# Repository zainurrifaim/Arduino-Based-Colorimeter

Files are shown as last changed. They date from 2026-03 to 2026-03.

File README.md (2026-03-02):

# 🎨 Arduino-Based Colorimeter

> **IoT RGB Colorimeter (LDR + LED)** — A cost-effective, educational light absorption measurement system

A simple yet powerful colorimeter built using an Arduino, an RGB LED, and a Light Dependent Resistor (LDR). This project supports both **physical hardware implementation** and **Tinkercad simulation**, making it perfect for learning and prototyping.

---

## 📑 Contents

- [Objective](#-objective)
- [Specifications](#-specifications)
- [Features](#-features)
- [Mathematical Principle](#-mathematical-principle)
- [Try It Out](#-try-it-out)
- [How to Use](#-how-to-use)
- [Project Structure](#-project-structure)

---

## 📋 Objective

Measure the **absorbance of liquid samples** across three primary wavelengths (Red, Green, and Blue) using the **Beer-Lambert Law principle**. This device quantifies how much light is absorbed by a solution, enabling:

- Determination of substance concentration
- Color characteristic analysis  
- Educational IoT demonstrations

---

## 🔧 Specifications

### Hardware Components

| Component | Description |
|---|---|
| **Microcontroller** | Arduino Uno (or compatible) |
| **Sensor** | 3-Pin LDR Module (or discrete LDR with 10kΩ resistor) |
| **Light Source** | RGB LED (Common Cathode recommended) |
| **Display** | 16×2 I2C LCD (Address 0x27) |
| **Controls** | 2× Tactile Push Buttons |
| **Resistors** | 3× 220Ω (LED protection) + 1× 10kΩ (optional, for discrete LDR) |

### Wiring and Pinout

#### 1️⃣ 3-Pin LDR Module

| Module Pin | Arduino Connection |
|---|---|
| **VCC** | 5V |
| **GND** | GND |
| **OUT (or S)** | A0 |

#### 2️⃣ RGB LED (Common Cathode)

| LED Pin | Arduino Connection | Details |
|---|---|---|
| **Common (Longest)** | GND | — |
| **Red Pin** | Pin 2 | via 220Ω resistor |
| **Green Pin** | Pin 3 | via 220Ω resistor |
| **Blue Pin** | Pin 4 | via 220Ω resistor |

#### 3️⃣ I2C LCD Display

| LCD Pin | Arduino Connection |
|---|---|
| **GND** | GND |
| **VCC** | 5V |
| **SDA** | A4 |
| **SCL** | A5 |

#### 4️⃣ Control Buttons

| Button | Arduino Pin | Other Connection |
|---|---|---|
| **Blank** | Pin 8 | GND |
| **Read** | Pin 9 | GND |

---

## ✨ Features

- **🌈 Multi-Spectrum Analysis** — Measures absorbance for Red, Green, and Blue wavelengths individually

- **⚙️ Intelligent Calibration** — Dedicated "Blank" mode to set 100% transmission baseline using a reference solution

- **📊 Signal Stability** — Digital averaging (multiple samples per reading) to filter sensor noise and electrical interference

- **🔄 Dual-Platform Support**
  - `colorimeter.ino` — Optimized for 3-pin LDR modules (Physical hardware)
  - `colorimeter_tinkercad.ino` — Adjusted for discrete 2-pin photoresistors (Tinkercad simulations)

- **💻 Real-time Feedback** — LCD interface with step-by-step instructions and instant numerical results (0.00 to 2.00+ absorbance units)

- **🛡️ Safety Guards** — Software checks prevent division-by-zero errors and prompt if calibration is skipped

---

## 📐 Mathematical Principle

The device calculates absorbance using the **Beer-Lambert Law**:

$$A = \log_{10}\left(\frac{I_{blank}}{I_{sample}}\right)$$

> **Note:** In the physical LDR module setup, the ratio is inverted in code to account for the specific resistance-to-voltage curve of the pre-built module.

---

## 🧪 Try It Out

**[View Interactive Tinkercad Simulation](https://www.tinkercad.com/things/clHeNK5QqYa-colorimeter/editel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)**

Test the logic and virtual circuit without building physical hardware!

---

## 🚀 How to Use

| Step | Action | Details |
|---|---|---|
| **1️⃣ Initialize** | Power the Arduino | Wait for "Ready!" message on LCD |
| **2️⃣ Calibrate** | Insert blank solution + press Pin 8 button | Sets 100% transmission baseline (use clear water) |
| **3️⃣ Measure** | Replace with sample + press Pin 9 button | Measures actual sample absorbance |
| **4️⃣ Analyze** | Read the results | LCD or Serial Monitor displays R, G, B absorbance values |

---

## 📂 Project Structure

```
Arduino-Based Colorimeter/
├── colorimeter/
│   └── colorimeter.ino           # Physical hardware version (3-pin LDR)
├── tinkercad_simulation/
│   └── colorimeter_tinkercad.ino # Simulation version (discrete photoresistor)
├── CAD/                          # 3D models and hardware designs
└── README.md                     # This file
```

---

## 💡 Tips & Troubleshooting

- **Calibration is Key** — Accurate blank readings directly impact measurement accuracy
- **Stable Environment** — Keep ambient light constant during measurements
- **Averaging** — The firmware automatically averages multiple readings to reduce noise
- **Serial Monitor** — Open the Serial Monitor (9600 baud) for detailed debugging info

---

## 📚 References

- **Beer-Lambert Law** — Fundamental principle for absorbance measurement
- **Arduino Documentation** — [arduino.cc](https://www.arduino.cc)
- **I2C LCD Displays** — Standard address 0x27 for 16×2 displays
- **Tinkercad** — [tinkercad.com](https://www.tinkercad.com) for circuit simulation

---

## ⭐ Perfect For

✓ Physics & Chemistry Education  
✓ IoT Projects & Prototyping  
✓ Sensor Integration Learning  
✓ Arduino Skill Development  
✓ DIY Analytical Instruments  

---

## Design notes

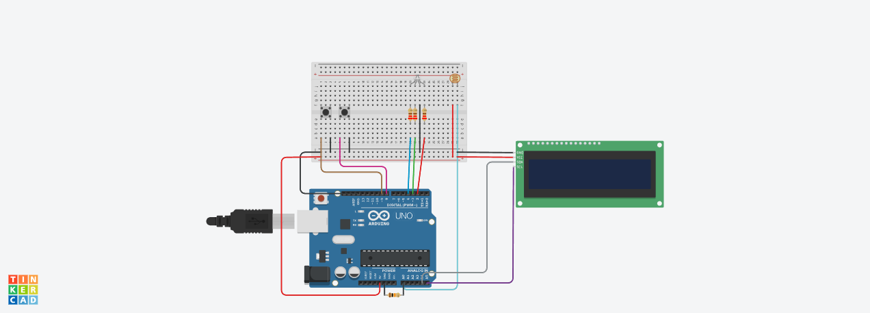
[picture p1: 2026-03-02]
tinkercad_simulation/colorimeter.png

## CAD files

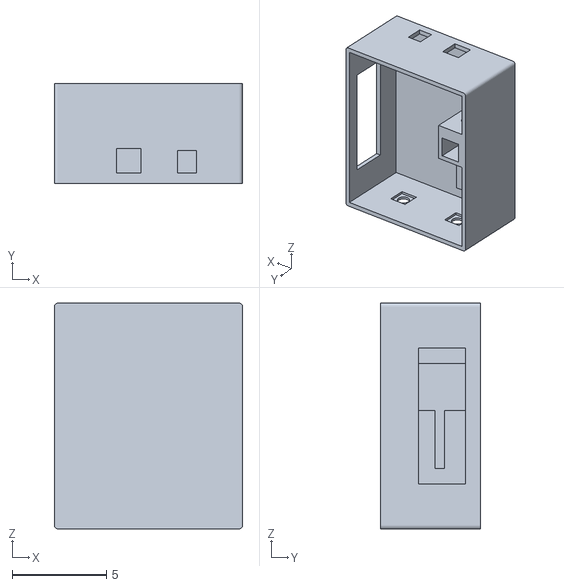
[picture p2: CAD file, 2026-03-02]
CAD/Case Colorymeter.stl
10.0 x 5.30 x 12.0

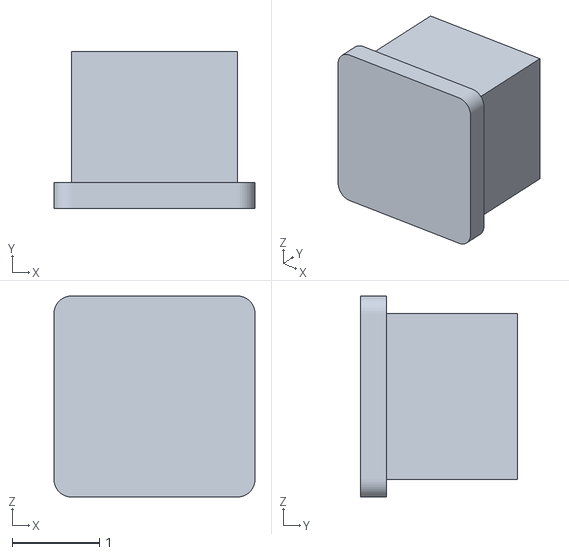
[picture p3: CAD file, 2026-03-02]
CAD/Tutup 2.stl
2.30 x 1.80 x 2.30

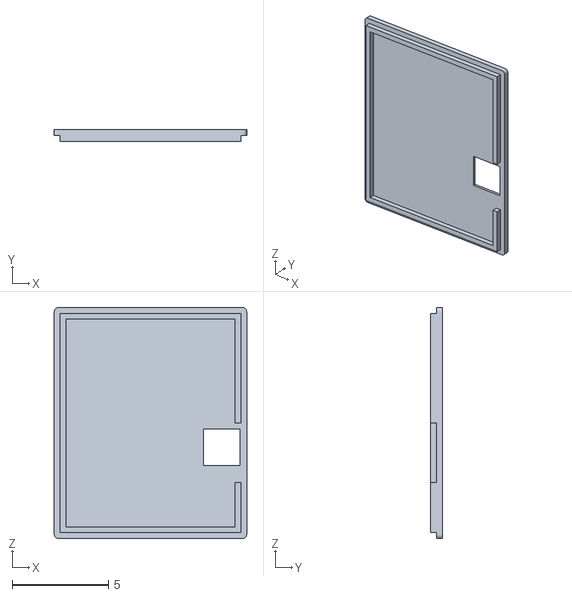
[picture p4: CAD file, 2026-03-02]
CAD/Cover 1 rev.stl
10.0 x 0.6 x 12.0

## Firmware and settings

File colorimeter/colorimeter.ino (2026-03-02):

/**
 * Final Colorimeter Sketch
 * * Description:
 * This code runs a simple colorimeter using an LDR, an RGB LED, and an I2C LCD.
 * It follows the Beer-Lambert law to calculate the absorbance of a sample.
 * * Features:
 * - Two-button operation: one for calibrating with a blank, one for measuring a sample.
 * - Averaging of sensor readings to reduce noise and improve accuracy.
 * - Clear user prompts on a 16x2 I2C LCD display.
 * - Robust button handling with debounce and single-press detection.
 * - Safe absorbance calculation with checks for calibration and division by zero.
 * * Hardware Setup:
 * - Arduino Uno (or similar)
 * - I2C LCD 16x2 (Address 0x27)
 * - Sensor: LDR on pin A0
 * - LEDs: Red on pin 2, Green on pin 3, Blue on pin 4
 * - Buttons: Blank/Calibrate on pin 8, Read/Measure on pin 9
 */

#include <Wire.h>
#include <LiquidCrystal_I2C.h>
#include <math.h> // For the log10() function

// Initialize the LCD display
LiquidCrystal_I2C lcd(0x27, 16, 2);

// --- Configuration Constants ---
const int numReadings = 10;      // Number of sensor readings to average for stability
const int sensorDelay = 10;      // Delay between individual readings (ms)
const int ledStabilizeTime = 50; // Time to wait for LED to reach full brightness

// --- Pin Definitions ---
const int sensorPin = A0;
const int ledRedPin = 2;
const int ledGreenPin = 3;
const int ledBluePin = 4;
const int buttonBlankPin = 8;
const int buttonReadPin = 9;

// --- Global Variables ---
double blankRed = 0, blankGreen = 0, blankBlue = 0;
double sampleRed = 0, sampleGreen = 0, sampleBlue = 0;
double absRed = 0, absGreen = 0, absBlue = 0;

// Flag to track whether calibration has been completed
bool isCalibrated = false;

void setup() {
  Serial.begin(9600);
  
  // Initialize the LCD and turn on the backlight
  lcd.init();
  lcd.backlight();
  lcd.setCursor(0, 0);
  lcd.print("Colorimeter");
  lcd.setCursor(0, 1);
  lcd.print("Initializing...");
  delay(2000);
  lcd.clear();

  // Set pin modes
  pinMode(ledRedPin, OUTPUT);
  pinMode(ledGreenPin, OUTPUT);
  pinMode(ledBluePin, OUTPUT);
  pinMode(sensorPin, INPUT);
  pinMode(buttonBlankPin, INPUT_PULLUP);
  pinMode(buttonReadPin, INPUT_PULLUP);
  
  Serial.println("Colorimeter Ready!");
  lcd.setCursor(0, 0);
  lcd.print("Ready!");
  lcd.setCursor(0, 1);
  lcd.print("Press Calibrate");
}

void loop() {
  // Check for Blank/Calibrate button press
  if (digitalRead(buttonBlankPin) == LOW) {
    delay(50); // Debounce delay
    calibrateBlank();
    // Wait for the button to be released to prevent re-triggering
    while(digitalRead(buttonBlankPin) == LOW);
  }
  
  // Check for Read/Measure button press
  if (digitalRead(buttonReadPin) == LOW) {
    delay(50); // Debounce delay
    measureSample();
    // Wait for the button to be released
    while(digitalRead(buttonReadPin) == LOW);
  }
}

// Function to handle blank calibration
void calibrateBlank() {
  lcd.clear();
  lcd.setCursor(0, 0);
  lcd.print("Insert Blank...");
  lcd.setCursor(0, 1);
  lcd.print("Calibrating...");
  
  // Take readings for all three colors
  blankRed = averageLDR(ledRedPin);
  blankGreen = averageLDR(ledGreenPin);
  blankBlue = averageLDR(ledBluePin);
  
  isCalibrated = true; // Set the calibration flag
  
  lcd.clear();
  lcd.setCursor(0, 0);
  lcd.print("Calibration OK!");
  Serial.println("Blank Calibration Done!");
  delay(1500);
  
  lcd.clear();
  lcd.print("Ready to Read");
}

// Function to measure sample absorbance
void measureSample() {
  // First, check if calibration has been performed
  if (!isCalibrated) {
    showError("Please Calibrate!");
    return;
  }
  
  lcd.clear();
  lcd.setCursor(0, 0);
  lcd.print("Insert Sample...");
  lcd.setCursor(0, 1);
  lcd.print("Measuring...");
  
  // Take readings for the sample
  sampleRed = averageLDR(ledRedPin);
  sampleGreen = averageLDR(ledGreenPin);
  sampleBlue = averageLDR(ledBluePin);
  
  // Calculate absorbance for each color
  // Absorbance = log10(Sample / Blank)
  // LDR reading is higher for the sample (less light) and lower for the blank (more light).
  // This ensures the absorbance is a positive value.
  absRed   = (sampleRed > 0 && blankRed > 0) ? log10(sampleRed / blankRed) : 0;
  absGreen = (sampleGreen > 0 && blankGreen > 0) ? log10(sampleGreen / blankGreen) : 0;
  absBlue  = (sampleBlue > 0 && blankBlue > 0) ? log10(sampleBlue / blankBlue) : 0;
  
  displayResults();
}

// Function to average LDR readings for a specific LED
double averageLDR(int ledPin) {
  // Ensure all LEDs are off to prevent light interference
  digitalWrite(ledRedPin, LOW);
  digitalWrite(ledGreenPin, LOW);
  digitalWrite(ledBluePin, LOW);
  
  // Turn on the target LED and wait for it to stabilize
  digitalWrite(ledPin, HIGH);
  delay(ledStabilizeTime);
  
  long total = 0;
  for (int i = 0; i < numReadings; i++) {
    total += analogRead(sensorPin);
    delay(sensorDelay);
  }
  
  // Turn the LED off after reading
  digitalWrite(ledPin, LOW);
  
  // Return the average value
  return total / (double)numReadings;
}

// Function to display absorbance results on the LCD and Serial Monitor
void displayResults() {
  lcd.clear();
  
  // Display Red and Green absorbance on the first line
  lcd.setCursor(0, 0);
  lcd.print("R:");
  lcd.print(absRed, 2); // Print with 2 decimal places
  
  lcd.setCursor(8, 0);
  lcd.print("G:");
  lcd.print(absGreen, 2);
  
  // Display Blue absorbance on the second line
  lcd.setCursor(0, 1);
  lcd.print("B:");
  lcd.print(absBlue, 2);
  
  // Print results to Serial Monitor for logging
  Serial.println("Absorbance Readings:");
  Serial.print("R: "); Serial.println(absRed, 2);
  Serial.print("G: "); Serial.println(absGreen, 2);
  Serial.print("B: "); Serial.println(absBlue, 2);

  // The loop() function will wait for the button release, so no extra wait is needed here.
}

// Function to display a temporary error message
void showError(const char* message) {
  lcd.clear();
  lcd.setCursor(0, 0);
  lcd.print("Error:");
  lcd.setCursor(0, 1);
  lcd.print(message);
  delay(2000);
  lcd.clear();
  lcd.print("Ready!");
}

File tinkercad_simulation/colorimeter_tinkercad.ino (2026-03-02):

/**
 * Tinkercad Colorimeter Sketch
 * * Description:
 * This version is specifically adapted for Tinkercad using a discrete 2-pin 
 * photoresistor and a standard voltage divider circuit.
 * * * Tinkercad Hardware Setup:
 * - Arduino Uno
 * - I2C LCD 16x2 (Address 0x27)
 * - LEDs: Red on pin 2, Green on pin 3, Blue on pin 4
 * - Buttons: Blank/Calibrate on pin 8, Read/Measure on pin 9
 * - PHOTO SENSOR WIRING: 
 * - Photoresistor Leg 1: 5V
 * - Photoresistor Leg 2: A0 AND to a 10k Ohm Resistor
 * - 10k Ohm Resistor other leg: GND
 */

#include <Wire.h>
#include <LiquidCrystal_I2C.h>
#include <math.h> 

LiquidCrystal_I2C lcd(0x27, 16, 2);

const int numReadings = 10;      
const int sensorDelay = 10;      
const int ledStabilizeTime = 50; 

const int sensorPin = A0;
const int ledRedPin = 2;
const int ledGreenPin = 3;
const int ledBluePin = 4;
const int buttonBlankPin = 8;
const int buttonReadPin = 9;

double blankRed = 0, blankGreen = 0, blankBlue = 0;
double sampleRed = 0, sampleGreen = 0, sampleBlue = 0;
double absRed = 0, absGreen = 0, absBlue = 0;

bool isCalibrated = false;

void setup() {
  Serial.begin(9600);
  
  lcd.init();
  lcd.backlight();
  lcd.setCursor(0, 0);
  lcd.print("Tinkercad Mode");
  lcd.setCursor(0, 1);
  lcd.print("Initializing...");
  delay(2000);
  lcd.clear();

  pinMode(ledRedPin, OUTPUT);
  pinMode(ledGreenPin, OUTPUT);
  pinMode(ledBluePin, OUTPUT);
  pinMode(sensorPin, INPUT);
  pinMode(buttonBlankPin, INPUT_PULLUP);
  pinMode(buttonReadPin, INPUT_PULLUP);
  
  Serial.println("Tinkercad Colorimeter Ready!");
  lcd.setCursor(0, 0);
  lcd.print("Ready!");
  lcd.setCursor(0, 1);
  lcd.print("Press Calibrate");
}

void loop() {
  if (digitalRead(buttonBlankPin) == LOW) {
    delay(50); 
    calibrateBlank();
    while(digitalRead(buttonBlankPin) == LOW);
  }
  
  if (digitalRead(buttonReadPin) == LOW) {
    delay(50); 
    measureSample();
    while(digitalRead(buttonReadPin) == LOW);
  }
}

void calibrateBlank() {
  lcd.clear();
  lcd.setCursor(0, 0);
  lcd.print("Insert Blank...");
  lcd.setCursor(0, 1);
  lcd.print("Calibrating...");
  
  blankRed = averageLDR(ledRedPin);
  blankGreen = averageLDR(ledGreenPin);
  blankBlue = averageLDR(ledBluePin);
  
  isCalibrated = true; 
  
  lcd.clear();
  lcd.setCursor(0, 0);
  lcd.print("Calibration OK!");
  Serial.println("Blank Calibration Done!");
  delay(1500);
  
  lcd.clear();
  lcd.print("Ready to Read");
}

void measureSample() {
  if (!isCalibrated) {
    showError("Please Calibrate!");
    return;
  }
  
  lcd.clear();
  lcd.setCursor(0, 0);
  lcd.print("Insert Sample...");
  lcd.setCursor(0, 1);
  lcd.print("Measuring...");
  
  sampleRed = averageLDR(ledRedPin);
  sampleGreen = averageLDR(ledGreenPin);
  sampleBlue = averageLDR(ledBluePin);
  
  // TINKERCAD MATH ADJUSTMENT:
  // With the standard Tinkercad voltage divider (LDR to 5V, Resistor to GND),
  // more light = a higher analog value. 
  // Therefore, Blank (high light) > Sample (low light).
  // Absorbance = log10(Blank / Sample)
  absRed   = (sampleRed > 0 && blankRed > 0) ? log10(blankRed / sampleRed) : 0;
  absGreen = (sampleGreen > 0 && blankGreen > 0) ? log10(blankGreen / sampleGreen) : 0;
  absBlue  = (sampleBlue > 0 && blankBlue > 0) ? log10(blankBlue / sampleBlue) : 0;
  
  displayResults();
}

double averageLDR(int ledPin) {
  digitalWrite(ledRedPin, LOW);
  digitalWrite(ledGreenPin, LOW);
  digitalWrite(ledBluePin, LOW);
  
  digitalWrite(ledPin, HIGH);
  delay(ledStabilizeTime);
  
  long total = 0;
  for (int i = 0; i < numReadings; i++) {
    total += analogRead(sensorPin);
    delay(sensorDelay);
  }
  
  digitalWrite(ledPin, LOW);
  return total / (double)numReadings;
}

void displayResults() {
  lcd.clear();
  lcd.setCursor(0, 0);
  lcd.print("R:");
  lcd.print(absRed, 2); 
  
  lcd.setCursor(8, 0);
  lcd.print("G:");
  lcd.print(absGreen, 2);
  
  lcd.setCursor(0, 1);
  lcd.print("B:");
  lcd.print(absBlue, 2);
  
  Serial.println("Absorbance Readings:");
  Serial.print("R: "); Serial.println(absRed, 2);
  Serial.print("G: "); Serial.println(absGreen, 2);
  Serial.print("B: "); Serial.println(absBlue, 2);
}

void showError(const char* message) {
  lcd.clear();
  lcd.setCursor(0, 0);
  lcd.print("Error:");
  lcd.setCursor(0, 1);
  lcd.print(message);
  delay(2000);
  lcd.clear();
  lcd.print("Ready!");
}
